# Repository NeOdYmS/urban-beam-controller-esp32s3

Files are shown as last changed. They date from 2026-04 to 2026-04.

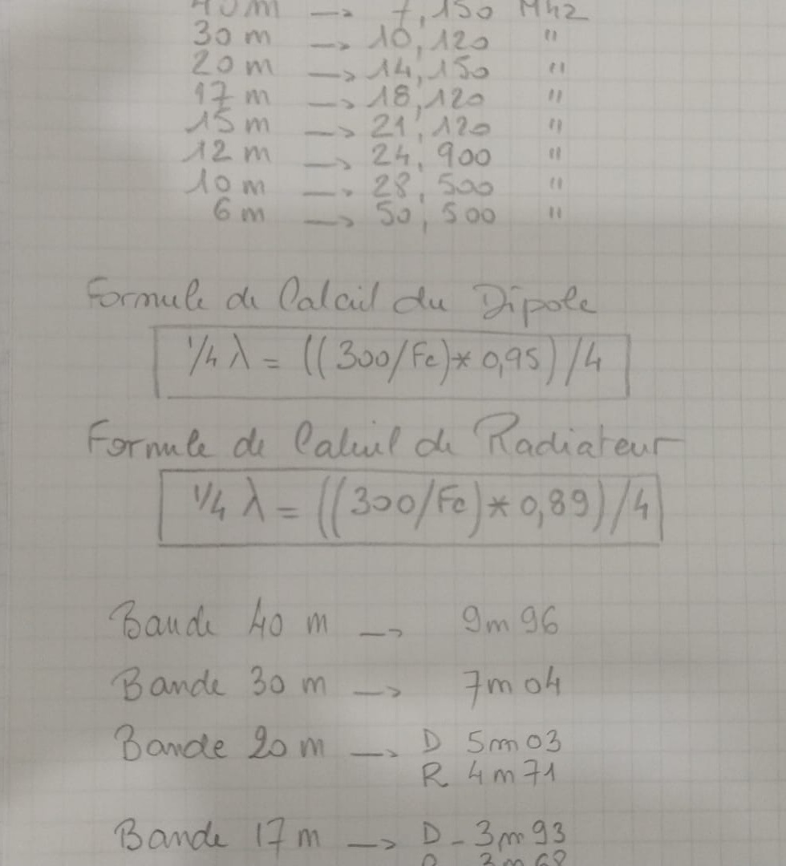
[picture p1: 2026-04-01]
PHOTO-2026-04-01-10-57-42.jpg

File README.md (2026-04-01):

# URBAN BEAM controlLer - ESP32-S3 Ethernet

Projet de controle d'antenne avec ESP32-S3 Ethernet et 2 axes moteurs pas a pas:

- Axe 1: ajustement dipole
- Axe 2: ajustement reflector

Strategie de reglage:

1. pre-positionnement par formule selon la frequence,
2. optimisation finale par tatonnement en fonction du ROS (SWR) mesure.

## Captures et apercus

### Capture interface web

Capture interface web

### Apercu schema electronique

Apercu schema

### Apercu board PCB

Apercu board

## Fonctions implementees

- Pilotage 2 axes STEP/DIR/ENABLE avec AccelStepper.
- 2 fins de course par axe (min/max, logique active LOW).
- Serveur HTTP embarque en Ethernet SPI (W5500).
- API HTTP:
  - /api/state
  - /api/frequency?mhz=...
  - /api/auto?on=1|0
  - /api/jog?motor=0|1&delta=...
  - /api/home?motor=0|1
  - /api/stop?motor=0|1
- Affichage SWR temps reel avec graphe live.
- Prepositionnement theorique:
  - Dipole: 1/4 lambda = ((300 / Fe) * 0.95) / 4
  - Reflector: 1/4 lambda = ((300 / Fe) * 0.89) / 4
- Auto-reglage par tatonnement SWR:
  - alternance des axes,
  - inversion du sens si la mesure ne s'ameliore pas,
  - pas adaptatif.

## Arborescence utile

- src/main.cpp: firmware complet.
- platformio.ini: environnement PlatformIO et dependances.
- hardware/fusion360/urban_beam_measurement_start.sch: base schema Fusion 360.
- hardware/fusion360/urban_beam_measurement_start.brd: base board Fusion 360.
- hardware/fusion360/measurement_design_notes.md: notes design carte mesure.

## Parametres a adapter pour Waveshare ESP32-S3-ETH-8DI-8RO-C

Dans src/main.cpp:

- broches Ethernet SPI: ETH_MISO_PIN, ETH_MOSI_PIN, ETH_SCK_PIN, ETH_CS_PIN, ETH_RST_PIN.
- broches moteurs/fins de course: motorPins.
- broches ADC de mesure SWR: FORWARD_POWER_ADC_PIN, REFLECTED_POWER_ADC_PIN.
- calibration mecanique:
  - DIPOLE_REF_LENGTH_MM, REFLECTOR_REF_LENGTH_MM
  - DIPOLE_REF_STEPS, REFLECTOR_REF_STEPS
  - DIPOLE_STEPS_PER_MM, REFLECTOR_STEPS_PER_MM

## Calibration SWR

Le calcul SWR actuel est une approximation de demarrage a partir des tensions AD8307.

Etapes recommandees:

1. calibrer Vf et Vr avec charges connues,
2. etablir la conversion tension -> puissance,
3. valider le SWR sur charge 50 ohms puis antenne reelle.

## Build et flash

```bash
pio run
pio run -t upload
pio device monitor
```

Au boot, l'adresse IP Ethernet est affichee sur le port serie:

```text
Ethernet IP: x.x.x.x
```

## Creation repository GitHub

Option en ligne de commande (si gh est installe et authentifie):

```bash
git init
git add .
git commit -m "Initial commit: URBAN BEAM ESP32-S3 Ethernet controller"
gh repo create urban-beam-controller --public --source=. --remote=origin --push
```

Option manuelle:

1. creer un repo vide sur GitHub,
2. lier le remote:

```bash
git remote add origin <URL_DU_REPO>
git branch -M main
git push -u origin main
```

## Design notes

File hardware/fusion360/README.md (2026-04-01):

# Fusion 360 - carte complementaire de mesure SWR (debut)

Ce dossier contient un point de depart pour la carte analogique de mesure SWR basee sur AD8307, a raccorder a l'ESP32-S3 Ethernet.

## Contenu

- `urban_beam_measurement_start.sch`: squelette schematique Eagle/Fusion 360.
- `urban_beam_measurement_start.brd`: squelette board Eagle/Fusion 360 (80 x 60 mm).
- `measurement_design_notes.md`: architecture electronique recommandee.
- `measurement_bom_start.csv`: BOM de depart.

## Objectif de la carte complementaire

- Mesure puissance directe (Vf) et reflechie (Vr) via coupleur directionnel.
- Detection logarithmique via 2x AD8307.
- Filtrage analogique et protection ADC.
- Sortie analogique vers 2 ADC ESP32-S3.
- Alimentation 5V -> 3V3 faible bruit pour etage mesure.

## Import dans Fusion 360

1. Ouvrir Fusion 360 Electronics.
2. Importer `urban_beam_measurement_start.sch`.
3. Importer `urban_beam_measurement_start.brd`.
4. Completer les composants reels (librairies AD8307, SMA, op-amp, connecteurs).

## Notes

- Les fichiers `.sch/.brd` fournis ici sont un point de demarrage structurel.
- Les empreintes et regles RF doivent etre adaptees a ton atelier (impedance, stackup, largeur microstrip).

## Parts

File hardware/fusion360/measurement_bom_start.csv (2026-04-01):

Ref | Qty | Value | Package | Description
J1 | 1 | BNC-F | BNC panel mount | RF input from TX
J2 | 1 | BNC-F | BNC panel mount | RF output to antenna
J3 | 1 | PinHeader 1x6 | 2.54mm | 5V GND SWR_ADC FREQ_OUT AGND RSV
T1 | 1 | FT37-43 bifilaire | through-hole | Coupleur directionnel ~20dB
U1 | 1 | LM311 | SOIC-8 | Comparateur RF → signal carré
U2 | 1 | 74HC4040 | SOIC-16 ou DIP-16 | Prescaler ÷256 pour compteur fréquence
U3 | 1 | LDO 3V3 | SOT-223 | Régulateur faible bruit pour analogique
U4 | 1 | MCP6002 | SOIC-8 | Buffer op-amp pour sortie SWR (optionnel)
D1-D2 | 2 | 1N5711 | SOD-323 | Diodes Schottky détectrices FWD/REV
R1-R3 | 3 | 50R 1% | 0603 | Pont résistif VSWR
R* | 6 | 1k-100k | 0603 | Résistances filtre/protection/adaptation
C* | 10 | 100n/1u | 0603/0805 | Découplage et filtrage
D3 | 1 | ESD clamp | SOT-23 | Protection entrée ADC ESP32

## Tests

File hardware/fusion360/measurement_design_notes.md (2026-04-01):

# Carte mesure SWR inline – Design notes

PCB séparé, placé à côté de l'ESP32-S3.
S'insère dans la chaîne TX → antenne via BNC IN / BNC OUT.

## 1) Architecture

```
[TX/transceiver]
      |
    BNC IN ──┐
             [coupleur directionnel]
    BNC OUT ─┘        |            |
                   FWD tap      REV tap
                      |            |
                  [détecteur]  [détecteur]
                      |            |
                   V_fwd        V_rev
                      |            |
                  [pont résistif / calcul SWR]
                      |
                  sortie DC ──► SWR_ADC (GPIO 1 vers ESP32)
                      |
              [comparateur LM311]
                      |
              [prescaler 74HC4040 ÷256]
                      |
                  FREQ_OUT ──► FREQ_COUNTER (GPIO 2 vers ESP32 PCNT)
```

Le coupleur directionnel prélève une fraction du signal forward
et reflected sans perturber la chaîne TX → antenne.

## 2) Coupleur directionnel

- Type: transformateur bifilaire sur tore ferrite (FT37-43 ou similaire).
- Couplage ~20 dB pour puissances 1-100 W.
- Alternative: coupleur Stockton (2 tores + résistances).
- Impédance caractéristique: 50 Ω.
- BNC IN: entrée depuis le TX.
- BNC OUT: sortie vers l'antenne.

## 3) Détection SWR

Deux approches possibles:

### a) Diodes + pont résistif (design K6BEZ simple)
- 3× 50 Ω (1%), 2× diodes Schottky (1N5711, BAT46, AA143).
- Sortie FWD/REV redressée.
- MCP6002 en buffer ou sommateur pour produire une tension
  proportionnelle au SWR.
- Filtrage RC (10k + 100nF) avant sortie ADC.

### b) AD8307 dual path (log detector, meilleure dynamique)
- AD8307 #1 sur voie FWD, AD8307 #2 sur voie REV.
- Sortie log vidéo (25 mV/dB, 92 dB de dynamique).
- Différence des deux sorties → proportionnel au return loss.
- Filtrage RC avant ADC.

Dans les deux cas, la sortie est une tension DC unique envoyée
sur le GPI `SWR_ADC` (GPIO 1 de l'ESP32-S3).

## 4) Détection automatique de fréquence

L'ADC de l'ESP32-S3 est trop lent pour échantillonner du HF
(1.8-30 MHz) directement.

Solution: compteur d'impulsions matériel.

- **LM311** (comparateur): convertit le signal RF (tap FWD du coupleur)
  en signal carré 0/3.3V compatible logique.
- **74HC4040** (compteur binaire 12 bits): prescaler ÷256.
  - Sortie Q8 (÷256) → GPIO 2 de l'ESP32-S3.
  - Fréquence max en entrée: 30 MHz → sortie: ~117 kHz.
- L'ESP32-S3 utilise le périphérique **PCNT** (Pulse Counter) pour
  compter les fronts montants sur une fenêtre de 100 ms.
- Calcul: `freq_Hz = count × 256 / 0.1`
- Résolution: ~2.56 kHz (suffisant pour identifier la bande HF).

## 5) Interface vers ESP32-S3

Connecteur J3 (pin header 1×6, 2.54mm):

| Pin | Signal | Direction | GPIO ESP32 |
|-----|---|---|---|
| 1 | +5V | → carte | — |
| 2 | GND | commun | GND |
| 3 | SWR_ADC | → ESP32 | GPIO 1 |
| 4 | FREQ_OUT (÷256)| → ESP32 | GPIO 2 |
| 5 | AGND | commun | — |
| 6 | réservé | — | — |

## 6) Alimentation

- 5V depuis carte ESP32 via J3 pin 1.
- Régulateur 3.3V local (LDO faible bruit) pour LM311 et logique.
- Découplage: 100nF + 1µF par IC.

## 7) Layout PCB

- Dimensions: ~60×40 mm.
- BNC IN et BNC OUT en bord de carte, côte à côte.
- Tore du coupleur au centre, pistes RF courtes.
- Zone analogique (détecteurs) séparée de zone numérique (74HC4040).
- Plan de masse continu sous les pistes RF.
- Connecteur J3 en bord opposé aux BNC.

## 8) Calibration logicielle

Utiliser des charges connues (50, 100, 150, 200 Ω) correspondant à
des SWR de 1, 2, 3, 4 dans un système 50 Ω.

- Mesurer la tension ADC pour chaque charge.
- Ajuster le mapping linéaire dans le firmware:
  `SWR = 1.0 + (adc_voltage / 3.3) × (SWR_MAX - 1.0)`
- Ou construire une LUT / regression si la réponse n'est pas linéaire.

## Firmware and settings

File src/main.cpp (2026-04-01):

// ============================================================================
// URBAN BEAM – Inline SWR Meter + Stepper Controller
// ESP32-S3 + W5500 Ethernet
//
// Architecture:
//   [TX] --BNC IN--> [coupleur directionnel] --BNC OUT--> [antenne]
//                          |
//                   [carte mesure SWR]  (PCB séparé, à côté de l'ESP)
//                          |
//                    GPI: ADC_SWR (tension proportionnelle au ROS)
//                          |
//                   [ESP32-S3  Waveshare]
//                     |             |
//                GPO: step/dir   Ethernet web UI
//                     |
//              [boîtier drivers moteurs]  (externe)
//                     |           |
//               axe dipole   axe reflector
//
// Fréquence: saisie manuelle OU détection auto via compteur PCNT
//            (comparateur LM311 + prescaler 74HC4040 ÷256 → GPIO)
// ============================================================================

#include <Arduino.h>
#include <SPI.h>
#include <Ethernet.h>
#include <AccelStepper.h>
#include <driver/pcnt.h>

namespace {

// ── Pin definitions ──────────────────────────────────────────────────────────

// GPO: stepper control (vers boîtier drivers externe).
struct MotorPins {
  uint8_t step;
  uint8_t dir;
  uint8_t enable;
  uint8_t limitMin;
  uint8_t limitMax;
};

enum AxisId : uint8_t { AXIS_DIPOLE = 0, AXIS_REFLECTOR = 1 };

MotorPins motorPins[2] = {
    {4, 5, 6, 7, 15},   // Dipole
    {16, 17, 18, 8, 3},  // Reflector
};

// GPI: SWR measurement – single analog input from measurement board.
// The board outputs a DC voltage proportional to VSWR (e.g. 0-3.3V → 1:1–∞).
constexpr uint8_t SWR_ADC_PIN = 1;

// GPI: Frequency counter input (after prescaler ÷256).
// On the measurement PCB: RF tap → LM311 comparator → 74HC4040 ÷256 → this pin.
constexpr uint8_t FREQ_COUNTER_PIN = 2;

// Ethernet (W5500 over SPI).
constexpr uint8_t ETH_MISO_PIN = 13;
constexpr uint8_t ETH_MOSI_PIN = 11;
constexpr uint8_t ETH_SCK_PIN  = 12;
constexpr uint8_t ETH_CS_PIN   = 10;
constexpr int8_t  ETH_RST_PIN  = 9;

// ── Motor parameters ─────────────────────────────────────────────────────────

constexpr float MAX_SPEED_STEPS_S = 1800.0f;
constexpr float ACCEL_STEPS_S2    = 1200.0f;
constexpr long  MAX_TRAVEL_STEPS[2] = {120000, 120000};

constexpr float DIPOLE_REF_LENGTH_MM    = 9960.0f;
constexpr float REFLECTOR_REF_LENGTH_MM = 9600.0f;
constexpr long  DIPOLE_REF_STEPS        = 42000;
constexpr long  REFLECTOR_REF_STEPS     = 45000;
constexpr float DIPOLE_STEPS_PER_MM     = -3.8f;
constexpr float REFLECTOR_STEPS_PER_MM  = -3.5f;

// ── Auto-tune ────────────────────────────────────────────────────────────────

constexpr float    SWR_TARGET           = 1.30f;
constexpr float    SWR_HIGH_MARGIN      = 0.10f;
constexpr float    SWR_IMPROVEMENT_HYST = 0.02f;
constexpr long     AUTO_MIN_STEP        = 8;
constexpr long     AUTO_MAX_STEP        = 240;
constexpr uint32_t AUTO_UPDATE_MS       = 900;

// ── ADC ──────────────────────────────────────────────────────────────────────

constexpr float ADC_VREF = 3.30f;
constexpr int   ADC_MAX  = 4095;

// SWR conversion: the measurement board outputs a voltage.
// Linear mapping: 0V → SWR 1.0, 3.3V → SWR_VOLTAGE_MAX_SWR.
// Adjust after real calibration.
constexpr float SWR_VOLTAGE_MAX_SWR = 10.0f;

constexpr uint32_t SWR_SAMPLE_MS = 300;

// ── Frequency counter ────────────────────────────────────────────────────────
// The 74HC4040 divides the RF frequency by 256.
// PCNT counts rising edges over a gate period.
// Measured frequency = (count * 256) / gate_seconds.

constexpr uint16_t FREQ_PRESCALER   = 256;
constexpr uint32_t FREQ_GATE_MS     = 100;   // 100ms gate → 10 Hz resolution × 256
constexpr pcnt_unit_t PCNT_UNIT     = PCNT_UNIT_0;

// ── Ethernet ─────────────────────────────────────────────────────────────────

byte ETH_MAC[] = {0x02, 0x55, 0x42, 0x10, 0x20, 0x33};
IPAddress fallbackIp(192, 168, 1, 70);
IPAddress fallbackDns(192, 168, 1, 1);
IPAddress fallbackGw(192, 168, 1, 1);
IPAddress fallbackMask(255, 255, 255, 0);
EthernetServer ethServer(80);

// ── Axis class ───────────────────────────────────────────────────────────────

class Axis {
public:
  explicit Axis(const MotorPins &pins)
      : pins_(pins), stepper_(AccelStepper::DRIVER, pins.step, pins.dir) {}

  void begin() {
    pinMode(pins_.enable, OUTPUT);
    digitalWrite(pins_.enable, LOW);
    pinMode(pins_.limitMin, INPUT_PULLUP);
    pinMode(pins_.limitMax, INPUT_PULLUP);
    stepper_.setMaxSpeed(MAX_SPEED_STEPS_S);
    stepper_.setAcceleration(ACCEL_STEPS_S2);
    stepper_.setCurrentPosition(0);
    homing_ = false;
    target_ = 0;
  }

  void update(long maxTravel) {
    if (homing_) {
      if (limitMinTriggered()) {
        homing_ = false;
        stepper_.stop();
        stepper_.setCurrentPosition(0);
        target_ = 0;
      } else {
        stepper_.runSpeed();
      }
      return;
    }
    long cur = stepper_.currentPosition();
    if (cur <= 0 && stepper_.distanceToGo() < 0) {
      stepper_.setCurrentPosition(0); stepper_.moveTo(0); target_ = 0; return;
    }
    if (cur >= maxTravel && stepper_.distanceToGo() > 0) {
      stepper_.setCurrentPosition(maxTravel); stepper_.moveTo(maxTravel); target_ = maxTravel; return;
    }
    if (stepper_.distanceToGo() < 0 && limitMinTriggered()) {
      stepper_.setCurrentPosition(0); stepper_.moveTo(0); target_ = 0; return;
    }
    if (stepper_.distanceToGo() > 0 && limitMaxTriggered()) {
      long lock = stepper_.currentPosition();
      stepper_.setCurrentPosition(lock); stepper_.moveTo(lock); target_ = lock; return;
    }
    stepper_.run();
  }

  void home()  { homing_ = true; stepper_.setSpeed(-700.0f); }
  void stop()  { homing_ = false; stepper_.stop(); target_ = stepper_.currentPosition(); }

  void moveTo(long abs, long maxT) {
    long c = constrain(abs, 0L, maxT);
    if (limitMinTriggered() && c < stepper_.currentPosition()) c = stepper_.currentPosition();
    if (limitMaxTriggered() && c > stepper_.currentPosition()) c = stepper_.currentPosition();
    target_ = c; stepper_.moveTo(c);
  }

  void jog(long delta, long maxT) { moveTo(stepper_.currentPosition() + delta, maxT); }

  long position()  { return stepper_.currentPosition(); }
  long target() const { return target_; }
  bool busy()      { return homing_ || stepper_.distanceToGo() != 0; }
  bool limitMinTriggered() const { return digitalRead(pins_.limitMin) == LOW; }
  bool limitMaxTriggered() const { return digitalRead(pins_.limitMax) == LOW; }

private:
  MotorPins pins_;
  AccelStepper stepper_;
  bool homing_ = false;
  long target_ = 0;
};

Axis axisDipole(motorPins[AXIS_DIPOLE]);
Axis axisReflector(motorPins[AXIS_REFLECTOR]);

// ── Global state ─────────────────────────────────────────────────────────────

float    currentFrequencyMHz     = 7.10f;
float    detectedFrequencyMHz    = 0.0f;   // auto-detected via PCNT
float    currentSwr              = 99.0f;
bool     freqAutoMode            = false;   // true = use detected frequency
float    autoBestSwr             = 99.0f;
bool     autoTuneEnabled         = false;
uint8_t  autoAxisRoundRobin      = 0;
int8_t   autoDirection[2]        = {1, 1};
long     autoStep[2]             = {60, 60};
uint32_t lastSwrSampleMs         = 0;
uint32_t lastAutoUpdateMs        = 0;
uint32_t lastFreqMeasureMs       = 0;
float    targetLengthDipoleMM    = 0.0f;
float    targetLengthReflectorMM = 0.0f;

// ── Frequency counter (PCNT) ─────────────────────────────────────────────────

void pcntInit() {
  pcnt_config_t cfg = {};
  cfg.pulse_gpio_num = FREQ_COUNTER_PIN;
  cfg.ctrl_gpio_num  = PCNT_PIN_NOT_USED;
  cfg.channel        = PCNT_CHANNEL_0;
  cfg.unit           = PCNT_UNIT;
  cfg.pos_mode       = PCNT_COUNT_INC;
  cfg.neg_mode       = PCNT_COUNT_DIS;
  cfg.lctrl_mode     = PCNT_MODE_KEEP;
  cfg.hctrl_mode     = PCNT_MODE_KEEP;
  cfg.counter_h_lim  = 32767;
  cfg.counter_l_lim  = 0;

  pcnt_unit_config(&cfg);
  pcnt_counter_pause(PCNT_UNIT);
  pcnt_counter_clear(PCNT_UNIT);
  pcnt_counter_resume(PCNT_UNIT);
}

// Returns frequency in MHz, or 0 if no signal.
float pcntMeasureFreqMHz() {
  pcnt_counter_clear(PCNT_UNIT);
  pcnt_counter_resume(PCNT_UNIT);
  delay(FREQ_GATE_MS);
  pcnt_counter_pause(PCNT_UNIT);

  int16_t count = 0;
  pcnt_get_counter_value(PCNT_UNIT, &count);

  if (count <= 1) return 0.0f;

  // freq_Hz = count * prescaler / gate_seconds
  double freqHz = static_cast<double>(count) * FREQ_PRESCALER /
                  (static_cast<double>(FREQ_GATE_MS) / 1000.0);
  return static_cast<float>(freqHz / 1e6);
}

// ── SWR measurement ──────────────────────────────────────────────────────────

float readSWR() {
  uint32_t sum = 0;
  for (int i = 0; i < 16; ++i) {
    sum += analogRead(SWR_ADC_PIN);
    delayMicroseconds(100);
  }
  float volts = (static_cast<float>(sum) / 16.0f / static_cast<float>(ADC_MAX)) * ADC_VREF;
  // Linear mapping: 0V→SWR 1.0, 3.3V→SWR_VOLTAGE_MAX_SWR.
  // Adjust this formula to match your measurement board's output characteristic.
  float swr = 1.0f + (volts / ADC_VREF) * (SWR_VOLTAGE_MAX_SWR - 1.0f);
  return max(swr, 1.0f);
}

// ── Antenna length formulas ──────────────────────────────────────────────────

float quarterWaveDipoleMM(float fMHz) {
  return ((300.0f / fMHz) * 0.95f) / 4.0f * 1000.0f;
}

float quarterWaveReflectorMM(float fMHz) {
  return ((300.0f / fMHz) * 0.89f) / 4.0f * 1000.0f;
}

long dipoleStepsFromMM(float mm) {
  float off = mm - DIPOLE_REF_LENGTH_MM;
  return constrain(static_cast<long>(DIPOLE_REF_STEPS + off * DIPOLE_STEPS_PER_MM),
                   0L, MAX_TRAVEL_STEPS[AXIS_DIPOLE]);
}

long reflectorStepsFromMM(float mm) {
  float off = mm - REFLECTOR_REF_LENGTH_MM;
  return constrain(static_cast<long>(REFLECTOR_REF_STEPS + off * REFLECTOR_STEPS_PER_MM),
                   0L, MAX_TRAVEL_STEPS[AXIS_REFLECTOR]);
}

// ── Apply frequency → move motors ────────────────────────────────────────────

void applyFrequency(float freqMHz) {
  currentFrequencyMHz = constrain(freqMHz, 1.0f, 60.0f);
  targetLengthDipoleMM    = quarterWaveDipoleMM(currentFrequencyMHz);
  targetLengthReflectorMM = quarterWaveReflectorMM(currentFrequencyMHz);

  axisDipole.moveTo(dipoleStepsFromMM(targetLengthDipoleMM),     MAX_TRAVEL_STEPS[AXIS_DIPOLE]);
  axisReflector.moveTo(reflectorStepsFromMM(targetLengthReflectorMM), MAX_TRAVEL_STEPS[AXIS_REFLECTOR]);

  autoBestSwr = 99.0f;
  autoStep[AXIS_DIPOLE] = 60;   autoStep[AXIS_REFLECTOR] = 60;
  autoDirection[AXIS_DIPOLE] = 1; autoDirection[AXIS_REFLECTOR] = 1;
}

// ── Auto-tune (tâtonnement) ──────────────────────────────────────────────────

void updateAutoTuning() {
  if (!autoTuneEnabled) return;
  if (axisDipole.busy() || axisReflector.busy()) return;

  uint32_t now = millis();
  if (now - lastAutoUpdateMs < AUTO_UPDATE_MS) return;
  lastAutoUpdateMs = now;

  if (currentSwr <= SWR_TARGET + SWR_HIGH_MARGIN) return;

  uint8_t axis = autoAxisRoundRobin % 2;
  autoAxisRoundRobin++;

  bool improved = (currentSwr + SWR_IMPROVEMENT_HYST) < autoBestSwr;
  if (improved) {
    autoBestSwr = currentSwr;
    autoStep[axis] = min(autoStep[axis] + 10, AUTO_MAX_STEP);
  } else {
    autoDirection[axis] = -autoDirection[axis];
    autoStep[axis] = max(autoStep[axis] / 2, AUTO_MIN_STEP);
  }

  long delta = static_cast<long>(autoDirection[axis] * autoStep[axis]);
  if (axis == AXIS_DIPOLE)
    axisDipole.jog(delta, MAX_TRAVEL_STEPS[AXIS_DIPOLE]);
  else
    axisReflector.jog(delta, MAX_TRAVEL_STEPS[AXIS_REFLECTOR]);
}

// ── Web UI ───────────────────────────────────────────────────────────────────

const char INDEX_HTML[] PROGMEM = R"HTML(
<!doctype html><html lang="fr"><head>
<meta charset="utf-8"/><meta name="viewport" content="width=device-width,initial-scale=1"/>
<title>URBAN BEAM – SWR Controller</title>
<style>
:root{--bg1:#0f172a;--bg2:#1e293b;--card:rgba(255,255,255,.09);--ok:#34d399;--warn:#f59e0b;--bad:#ef4444;--txt:#e2e8f0;--muted:#94a3b8;--accent:#22d3ee}
*{box-sizing:border-box}
body{margin:0;font-family:"IBM Plex Sans","Segoe UI",sans-serif;color:var(--txt);
  background:radial-gradient(circle at 10% 10%,#1d4ed8 0%,transparent 35%),
             radial-gradient(circle at 90% 20%,#0ea5e9 0%,transparent 30%),
             linear-gradient(165deg,var(--bg1),var(--bg2));min-height:100vh;padding:16px}
.g{display:grid;grid-template-columns:repeat(auto-fit,minmax(300px,1fr));gap:12px}
.c{background:var(--card);border:1px solid rgba(255,255,255,.13);border-radius:14px;padding:14px;backdrop-filter:blur(8px)}
h1{margin:0 0 10px;font-size:1.3rem}
h2{margin:0 0 6px;font-size:.95rem;color:#f8fafc}
.r{display:flex;gap:6px;flex-wrap:wrap;align-items:center;margin-top:6px}
.m{color:var(--muted);font-size:.85rem}
.badge{font-weight:700;color:#020617;background:#67e8f9;border-radius:999px;padding:3px 9px;font-size:.82rem}
button{background:rgba(15,23,42,.75);color:var(--txt);border:1px solid rgba(148,163,184,.5);border-radius:8px;padding:6px 10px;cursor:pointer;font-size:.82rem}
button:hover{border-color:var(--accent)}
button.active{border-color:var(--ok);background:rgba(52,211,153,.15)}
select,input{padding:5px 8px;border-radius:8px;border:1px solid rgba(148,163,184,.5);background:rgba(2,6,23,.7);color:var(--txt);font-size:.85rem}
input[type=number]{max-width:120px}
.swr-big{font-size:2.8rem;font-weight:800;text-align:center;margin:10px 0;letter-spacing:-.02em}
.swr-ok{color:var(--ok)}.swr-warn{color:var(--warn)}.swr-bad{color:var(--bad)}
.freq-big{font-size:1.4rem;font-weight:600;text-align:center;color:var(--accent)}
.info-row{display:flex;justify-content:space-between;padding:2px 0}
.info-row .label{color:var(--muted);font-size:.82rem}
.info-row .val{font-weight:600;font-size:.88rem}
</style></head><body>
<h1>URBAN BEAM – Controleur antenne HF</h1>
<div class="g">

<!-- SWR display -->
<section class="c">
  <h2>ROS / SWR</h2>
  <div id="swr" class="swr-big swr-warn">--</div>
  <div class="info-row"><span class="label">Ethernet</span><span class="val" id="ip">--</span></div>
</section>

<!-- Frequency -->
<section class="c">
  <h2>Frequence</h2>
  <div id="freqDisplay" class="freq-big">-- MHz</div>
  <div class="r">
    <button id="btnManual" class="active" onclick="setMode('manual')">Manuel</button>
    <button id="btnAuto" onclick="setMode('auto')">Auto (compteur)</button>
  </div>
  <div class="r" id="manualRow">
    <input id="freqIn" type="number" min="1" max="55" step="0.001" value="7.100"/>
    <label>MHz</label>
    <button onclick="applyFreq()">Appliquer</button>
  </div>
  <div class="r">
    <select id="bandSel" onchange="pickBand()">
      <option value="">-- Bande --</option>
      <option value="1.900">160m (1.9)</option>
      <option value="3.650">80m (3.65)</option>
      <option value="7.100" selected>40m (7.1)</option>
      <option value="10.125">30m (10.125)</option>
      <option value="14.175">20m (14.175)</option>
      <option value="18.118">17m (18.118)</option>
      <option value="21.225">15m (21.225)</option>
      <option value="24.940">12m (24.94)</option>
      <option value="28.500">10m (28.5)</option>
    </select>
  </div>
  <div class="m" style="margin-top:8px">Freq detectee: <b id="detFreq">--</b> MHz</div>
</section>

<!-- Antenna lengths -->
<section class="c">
  <h2>Longueurs antenne calculees</h2>
  <div class="info-row"><span class="label">Dipole 1/4&lambda;</span><span class="val" id="dipMM">-- mm</span></div>
  <div class="info-row"><span class="label">Reflector 1/4&lambda;</span><span class="val" id="refMM">-- mm</span></div>
  <div class="r"><span class="badge">Formule: (300/Fe &times; k) / 4</span></div>
</section>

<!-- Auto-tune -->
<section class="c">
  <h2>Ajustement auto (tatonnement)</h2>
  <div class="r">
    <button onclick="autoTune(1)">Activer</button>
    <button onclick="autoTune(0)">Stop</button>
  </div>
  <div class="m">Etat: <b id="autoSt">--</b></div>
  <div class="r"><span class="badge">Objectif SWR &le; 1.30</span></div>
</section>

<!-- Motor: Dipole -->
<section class="c">
  <h2>Axe Dipole</h2>
  <div class="info-row"><span class="label">Position</span><span class="val" id="m1pos">--</span></div>
  <div class="info-row"><span class="label">Fins de course</span><span class="val">min:<span id="m1min">--</span> max:<span id="m1max">--</span></span></div>
  <div class="r">
    <button onclick="jog(0,-500)">-500</button>
    <button onclick="jog(0,-100)">-100</button>
    <button onclick="jog(0,100)">+100</button>
    <button onclick="jog(0,500)">+500</button>
    <button onclick="home(0)">Home</button>
    <button onclick="stop(0)">Stop</button>
  </div>
</section>

<!-- Motor: Reflector -->
<section class="c">
  <h2>Axe Reflector</h2>
  <div class="info-row"><span class="label">Position</span><span class="val" id="m2pos">--</span></div>
  <div class="info-row"><span class="label">Fins de course</span><span class="val">min:<span id="m2min">--</span> max:<span id="m2max">--</span></span></div>
  <div class="r">
    <button onclick="jog(1,-500)">-500</button>
    <button onclick="jog(1,-100)">-100</button>
    <button onclick="jog(1,100)">+100</button>
    <button onclick="jog(1,500)">+500</button>
    <button onclick="home(1)">Home</button>
    <button onclick="stop(1)">Stop</button>
  </div>
</section>

</div>
<script>
function api(p){return fetch(p,{cache:'no-store'}).then(r=>r.json())}
function applyFreq(){
  const f=parseFloat(document.getElementById('freqIn').value||'7.1');
  fetch('/api/frequency?mhz='+f);
}
function pickBand(){
  const v=document.getElementById('bandSel').value;
  if(v){document.getElementById('freqIn').value=v;applyFreq()}
}
function setMode(m){
  fetch('/api/freqmode?mode='+m);
  document.getElementById('btnManual').className=m==='manual'?'active':'';
  document.getElementById('btnAuto').className=m==='auto'?'active':'';
}
function autoTune(on){fetch('/api/auto?on='+on)}
function jog(m,d){fetch('/api/jog?motor='+m+'&delta='+d)}
function home(m){fetch('/api/home?motor='+m)}
function stop(m){fetch('/api/stop?motor='+m)}

function swrClass(v){return v<=1.5?'swr-ok':v<=3?'swr-warn':'swr-bad'}

async function poll(){
  try{
    const s=await api('/api/state');
    const el=document.getElementById('swr');
    el.textContent=s.swr.toFixed(2);
    el.className='swr-big '+swrClass(s.swr);
    document.getElementById('freqDisplay').textContent=s.frequencyMHz.toFixed(3)+' MHz';
    document.getElementById('detFreq').textContent=s.detectedMHz>0?s.detectedMHz.toFixed(3):'aucun signal';
    document.getElementById('ip').textContent=s.ip;
    document.getElementById('dipMM').textContent=s.dipoleMM.toFixed(1)+' mm';
    document.getElementById('refMM').textContent=s.reflectorMM.toFixed(1)+' mm';
    document.getElementById('autoSt').textContent=s.autoTune?'ACTIF':'MANUEL';
    document.getElementById('m1pos').textContent=s.m[0].p;
    document.getElementById('m2pos').textContent=s.m[1].p;
    document.getElementById('m1min').textContent=s.m[0].lMin?'ON':'off';
    document.getElementById('m1max').textContent=s.m[0].lMax?'ON':'off';
    document.getElementById('m2min').textContent=s.m[1].lMin?'ON':'off';
    document.getElementById('m2max').textContent=s.m[1].lMax?'ON':'off';
    document.getElementById('btnManual').className=s.freqAuto?'':'active';
    document.getElementById('btnAuto').className=s.freqAuto?'active':'';
  }catch(_){}
}
setInterval(poll,500);poll();
</script></body></html>
)HTML";

// ── HTTP helpers ─────────────────────────────────────────────────────────────

String boolJSON(bool v) { return v ? "true" : "false"; }

String getArg(const String &query, const String &key) {
  int from = 0;
  while (from < static_cast<int>(query.length())) {
    int amp = query.indexOf('&', from);
    if (amp < 0) amp = query.length();
    int eq = query.indexOf('=', from);
    if (eq > from && eq < amp) {
      if (query.substring(from, eq) == key) return query.substring(eq + 1, amp);
    }
    from = amp + 1;
  }
  return "";
}

void sendHttp(EthernetClient &c, const char *status, const char *type, const String &body) {
  c.print("HTTP/1.1 "); c.println(status);
  c.print("Content-Type: "); c.println(type);
  c.println("Cache-Control: no-store");
  c.print("Content-Length: "); c.println(body.length());
  c.println("Connection: close");
  c.println();
  c.print(body);
}
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
void loop() {
  axisDipole.update(MAX_TRAVEL_STEPS[AXIS_DIPOLE]);
  axisReflector.update(MAX_TRAVEL_STEPS[AXIS_REFLECTOR]);

  handleHttpClient();
  Ethernet.maintain();

  uint32_t now = millis();

  // Periodic SWR reading.
  if (now - lastSwrSampleMs >= SWR_SAMPLE_MS) {
    lastSwrSampleMs = now;
    currentSwr = readSWR();
  }

  // Periodic frequency detection (every 500ms, non-blocking-ish).
  if (now - lastFreqMeasureMs >= 500) {
    lastFreqMeasureMs = now;
    detectedFrequencyMHz = pcntMeasureFreqMHz();
    // If in auto mode and a valid signal is detected, apply it.
    if (freqAutoMode && detectedFrequencyMHz >= 1.0f) {
      // Only re-apply if frequency changed significantly (>50 kHz).
      if (fabsf(detectedFrequencyMHz - currentFrequencyMHz) > 0.050f) {
        applyFrequency(detectedFrequencyMHz);
      }
    }
  }

  updateAutoTuning();
}

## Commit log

2026-04-01 Initial commit: URBAN BEAM ESP32-S3 Ethernet controller
    [measurement_bom_start.csv, urban_beam_measurement_start.brd, urban_beam_measurement_start.sch]
2026-04-01 refactor: simplified inline SWR meter architecture
    - Remove DDS/AD9850 sweep engine (not needed)
    - Single ADC input for SWR voltage from measurement board
    - PCNT frequency counter (LM311 + 74HC4040 prescaler ÷256)
    - Manual + auto frequency mode in web UI
    - Simplified web UI: SWR value, band selector, motor controls
    - Update measurement PCB design notes for inline BNC IN/OUT topology
    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
    [measurement_bom_start.csv]
